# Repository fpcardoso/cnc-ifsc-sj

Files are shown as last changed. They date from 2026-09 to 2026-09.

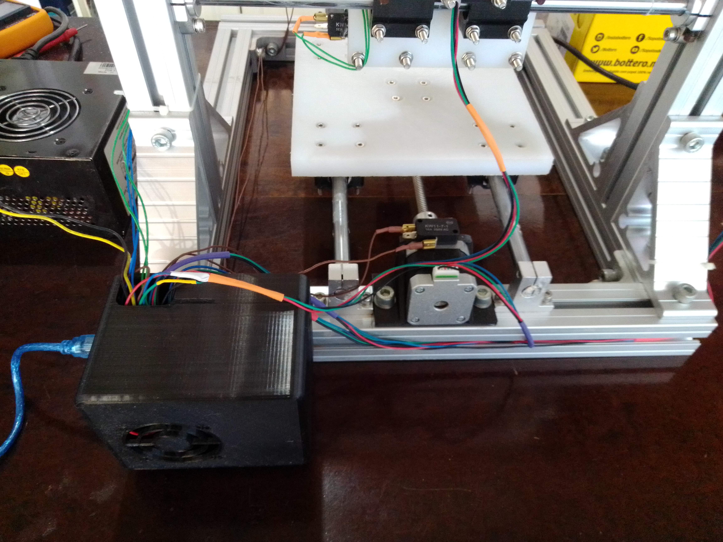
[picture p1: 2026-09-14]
imagens/IMG_20211114_110311.jpg

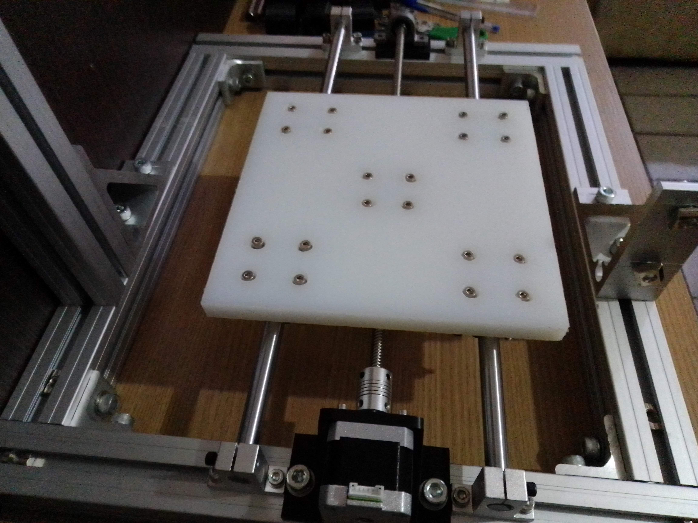
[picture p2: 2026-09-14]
imagens/IMG_20210815_180117.jpg

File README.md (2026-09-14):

# Desenvolvimento de uma fresadora CNC para confecção de antenas planares e PCIs

Este repositório contém os arquivos de modelagem, código-fonte e artefatos utilizados no desenvolvimento de uma **fresadora CNC de pequeno porte**, criada para a fabricação de **antenas planares** e **circuitos impressos (PCIs)** em ambiente acadêmico. O projeto foi desenvolvido como Trabalho de Conclusão de Curso no **Instituto Federal de Santa Catarina (IFSC) -- Câmpus São José**.

## Objetivo do Projeto

Construir uma fresadora CNC acessível, utilizando componentes de **baixo
custo**, **fácil aquisição** e **plataformas abertas**, permitindo:

-   Produção de antenas impressas;
-   Fabricação de PCIs simples por fresamento;

## Características Principais

-   Arquitetura: **CNC vertical de pórtico fixo**.
-   Eixos X, Y e Z controlados por motores **NEMA 17**.
-   Estrutura construída com **perfis de alumínio estrutural**.
-   Guias lineares com **eixos retificados de 12 mm e rolamentos
    LM12UU**.
-   Movimento por **fusos trapezoidais TR8** com castanhas
    **antifolga**.
-   Spindle baseado no motor **775** com suporte **ER11**.
-   Eletrônica simples:
    -   **Arduino Uno**
    -   **CNC Shield V3**
    -   **Drivers A4988**
    -   **Chaves de fim de curso**
-   Firmware: **Grbl** (open-source).
-   Compatível com softwares de envio de G-code, como **Universal Gcode Sender**.

## Documentação Completa

O documento completo do projeto, incluindo modelagem, lista
de materiais, testes, cálculos e guia de operação, está disponível em [TCC_DESENVOLVIMENTO_FRESADORA_CNC](https://repositorio.ifsc.edu.br/items/885bb8a0-5da8-42db-98ac-e9bbe950c8d6).

## Imagens e vídeos

Imagens e vídeos extras do processo de construção estão diponível em [Imagens](./imagens/)

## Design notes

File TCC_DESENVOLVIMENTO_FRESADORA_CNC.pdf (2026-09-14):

### INSTITUTO FEDERAL DE EDUCAÇÃO, CIÊNCIA E TECNOLOGIA

### DE SANTA CATARINA

### CAMPUS SÃO JOSÉ

### FELIPE DOS PASSOS CARDOSO

DESENVOLVIMENTO DE UMA FRESADORA CNC PARA CONFECÇÃO DE ANTENAS PLANARES

### SÃO JOSÉ

2025

### Felipe dos Passos Cardoso

### Desenvolvimento de uma fresadora CNC para confecção de antenas

### planares

Monografia apresentada ao Curso de Engenharia de Telecomunicações do Instituto Federal de Santa Catarina, para a obtenção do título de bacharel em Engenharia de Telecomunicações.

Área de concentração: Telecomunicações

Orientadora: Profa. Evanaska Maria Barbosa Nogueira, Dra.

### São José

### Felipe dos Passos Cardoso

### Desenvolvimento de uma fresadora CNC para confecção de antenas planares

Monografia apresentada ao Curso de Engenharia de Telecomunicações do Instituto Federal de Santa Catarina, para a obtenção do título de bacharel em Engenharia de Telecomunicações.

São José, 19 de dezembro de 2025.

Profa. Evanaska Maria Barbosa Nogueira, Dra.

Instituto Federal de Santa Catarina

Prof. Diego da Silva Medeiros, Dr.

Instituto Federal de Santa Catarina

Prof. Ramon Mayor Martins, Dr.

Instituto Federal de Santa Catarina

# RESUMO

Os dispositivos de comunicação sem fio exercem um papel fundamental na troca de informações e utilizam antenas como elementos essenciais para a transmissão e recepção de ondas eletromagnéticas. Com a crescente demanda por equipamentos mais compactos e eficientes, intensificam-se as pesquisas envolvendo antenas planares, que se destacam pela facilidade de integração e baixo perfil. Entretanto, o desenvolvimento desse tipo de antena apresenta desafios na etapa de fabricação, especialmente no que se refere à precisão e ao custo dos equipamentos necessários, o que pode limitar sua aplicação em ambientes acadêmicos. Uma alternativa para essa problemática é a utilização de máquinas de Comando Numérico Computadorizado (CNC) para a confecção das antenas por meio do processo de fresamento. Nesse contexto, este trabalho teve como objetivo o desenvolvimento de uma fresadora CNC de pequeno porte, utilizando componentes acessíveis, visando sua aplicação no ensino e na pesquisa. O projeto contemplou as etapas de concepção mecânica, integração eletrônica e implementação do sistema de controle. Os testes realizados permitiram validar o funcionamento do sistema de movimentação e do controle da máquina, bem como a execução de simulações completas de usinagem. Embora não tenha sido possível a fabricação física de uma antena planar devido a limitações no sistema de usinagem, os resultados obtidos demonstram a viabilidade da fresadora desenvolvida como uma plataforma funcional e passível de aprimoramentos futuros para aplicações acadêmicas.

Palavras-chave: Fresadora CNC. Antenas impressas. PCI. Prototipagem.

# ABSTRACT

Wireless communication devices play a fundamental role in information exchange and rely on antennas as essential components for the transmission and reception of electromagnetic waves. With the increasing demand for more compact and efficient equipment, research on planar antennas has intensified due to their low profile and ease of integration. However, the development of this type of antenna presents challenges in the manufacturing stage, particularly regarding precision and the high cost of machining equipment, which may limit its use in academic environments. An alternative to this issue is the use of Computer Numerical Control (CNC) machines to manufacture antennas through the milling process. In this context, this work aimed to develop a small-scale CNC milling machine using readily available components, with a focus on applications in teaching and research. The project included the mechanical design, electronic integration, and implementation of the control system. The performed tests validated the operation of the motion system and machine control, as well as complete machining simulations. Although the physical fabrication of a planar antenna was not achieved due to limitations in the machining system, the obtained results demonstrate the feasibility of the developed CNC machine as a functional platform with potential for future improvements in academic applications.

Keywords: CNC milling machine. Printed antennas. PCB. Prototyping.

# LISTA DE ILUSTRAÇÕES

Figura 17 – Imagens ilustrativas do fuso trapezoidal e da castanha antifolga . . . . 31

Figura 21 – Imagens ilustrativas dos suportes KP08 e SHF12 e do acoplador . . . . 33

Figura 28 – Imagem ilustrativa da fonte de alimentação utilizada na fresadora . . . 37

Figura 32 – Conjunto pillow blocks SC12UU customizados para mesa do eixo X . . 43

Figura 34 – Imagens ilustrativas da fresadora com sistemas de deslocamento . . . . 44

Figura 40 – Esquemático do circuito para conexão dos motores à CNC Shield . . . 49 Figura 41 – Esquemático do circuito para conexão das chaves de fim de curso . . . 50

Figura 43 – Esquemático do circuito do spindle com módulo relé e CNC Shield . . 51

Figura 49 – Dimensões do fuso trapezoidal e castanha antifolga em milímetros (mm) 66 Figura 50 – Imagens ilustrativas dos pillow blocks para rolamento e castanha antifolga 66

Figura 60 – Importação do código-fonte do firmware Grbl no software Arduino IDE 76 Figura 61 – Configuração para desabilitar o controle de velocidade do motor 775 . . 76 Figura 62 – Configuração para inverter lógico do pino de acionamento do motor 775 76

Figura 64 – Configurando Arduino Uno no software Universal Gcode Sender (UGS) 77 Figura 65 – Informação de conexão com o firmware no console do software UGS . . 77 Figura 66 – Valores padrões de parâmetros do firmware apresentados no UGS . . . 78

# LISTA DE QUADROS

Quadro 1 – Configurações de resolução de micropassos disponíveis para driver A4988 45

# LISTA DE TABELAS

Tabela 3 – Medidas e quantidades dos elementos mecânicos dimensionados . . . . 39 Tabela 4 – Descrição e valores das variáveis utilizadas no cálculo de steps/mm . . 53 Tabela 5 – Parâmetros ajustados no firmware Grbl para fresadora desenvolvida . . 54

# LISTA DE ABREVIATURAS E SIGLAS

CAD Computer-Aided Design.

CAM Computer-Aided Manufacturing.

CNC Comando Numérico Computadorizado.

IDE Integrated Development Environment.

IFSC Instituto Federal de Santa Catarina.

MDF Medium Density Fiberboard.

PCI Placa de Circuito Impresso.

UGS Universal Gcode Sender.

USB Universal Serial Bus.

# SUMÁRIO

APÊNDICES | 63

APÊNDICE A – LISTA DE COMPONENTES UTILIZADOS . . . . 64

APÊNDICE B – VISTAS DO MODELO 3D DA FRESADORA . . 71

APÊNDICE C – INSTALAÇÃO E PARAMETRIZAÇÃO DO FIRMWARE

APÊNDICE D – GUIA DE OPERAÇÃO DA FRESADORA CNC . . 79

# 1 INTRODUÇÃO

Dispositivos de comunicação sem fio são utilizados em diversos cenários, incluindo residências e setores industriais, desempenhando um papel essencial na troca de informações e conexões globais. Nesses equipamentos, as informações são transmitidas e recebidas por meio de ondas eletromagnéticas, o que torna as antenas um componente crucial na comunicação sem fio. Com os avanços tecnológicos contínuos, esses dispositivos estão se tornando mais complexos em termos de processamento e mais eficientes no consumo de energia, além dos tamanhos se tornarem cada vez mais compactos (PIRES; SILVA, 2017). Como resultado, a indústria está em busca de antenas menores e mais eficientes.

As antenas de microfita, incluindo patch, monopolo impresso e PIFA (Planar Inverted-F Antenna), são amplamente utilizadas em dispositivos de comunicações sem fio. As antenas do tipo patch possuem um elemento irradiante impresso sobre um substrato dielétrico, com um plano de terra oposto e se destacam pelo baixo custo, adaptabilidade a diferentes superfícies, capacidade de assumir vários formatos e tamanho compacto (OLIVEIRA, 2008). Isso possibilita sua integração em dispositivos móveis que compõem os sistemas de telecomunicações.

O desenvolvimento de antenas para dispositivos sem fio é resultado do aprofundamento em pesquisas e experimentações, especialmente aquelas envolvendo antenas impressas para as frequências de micro-ondas. Segundo Pires e Silva (2017), a diversidade de aplicações das antenas impressas, juntamente com questões como o acoplamento da linha de transmissão, diagrama de irradiação desejado, ganho necessário e polarização requerida, justifica amplamente a pesquisa e desenvolvimento contínuo dessas antenas. Isso tem como objetivo aprimorar as características e explorar novos cenários de utilização dessas antenas.

Projetar e fabricar antenas em substratos são atividades complexas que desafiam engenheiros e pesquisadores. A etapa de fabricação desempenha um papel crucial na produção de antenas impressas em substratos, mas a busca pela robustez e precisão resulta na utilização de equipamentos de alto custo. Esse custo elevado pode tornar inviável a utilização desses equipamentos em ambientes educacionais dentro de uma instituição. Uma solução promissora para essa etapa é a adoção de uma fresadora CNC de pequeno porte, uma máquina de usinagem que utiliza a tecnologia de Comando Numérico Computadorizado (CNC) para automatizar o processo de produção de peças, exigindo pouca intervenção do operador (POLASTRINI, 2016).

A usinagem abrange diversos processos de fabricação nos quais ocorre a remoção de material de forma controlada de um objeto original. Esses processos incluem o fresamento, a furação e o torneamento, resultando na criação de peças com a forma desejada (CAVENAGHI; CAVENAGHI; GONZALEZ, 2022). Uma fresadora CNC fabrica a peça por meio do fresamento, processo no qual a ferramenta gira enquanto a mesa movimenta a peça nos eixos longitudinal e transversal. Essa característica única diferencia o fresamento de outros processos de usinagem, proporcionando à fresadora a capacidade de executar uma ampla variedade de trabalhos com precisão (COSTA, 2003).

No câmpus São José do Instituto Federal de Santa Catarina (IFSC), o projeto de pesquisa e extensão intitulado Estudo e desenvolvimento de antenas planares de baixo custo¹ visou o aprofundamento dos estudos sobre antenas impressas e sua implementação em substratos de baixo custo. Buscando preencher, dessa forma, uma lacuna significativa no ensino e pesquisa na área de circuitos de radiofrequência na banda de micro-ondas. O projeto foi dividido em 2 eixos principais de atividades a serem executadas: 1) atividades para concepção e implementação das antenas e; 2) construção de uma máquina CNC para fabricação da antenas planejadas durante a execução do eixo 1.

Este trabalho tem como objetivo principal o desenvolvimento de uma fresadora CNC de pequeno porte e com baixo custo, integrando componentes de hardware e software abertos amplamente aceitos. A fresadora será voltada para a fabricação de antenas impressas, visando atender as necessidades do eixo 1 do projeto mencionando anteriormente. Além disso, a fresadora poderá ser utilizada na produção de outros circuitos impressos, auxiliando na modernização dos projetos integradores e enriquecendo o processo de aprendizagem nas disciplinas que envolvem eletrônica no câmpus São José do Instituto Federal de Santa Catarina (IFSC).

## 1.1 OBJETIVO GERAL

Desenvolver e fabricar uma fresadora CNC de pequeno porte, possibilitando a confecção de antenas planares e outros circuitos impressos.

## 1.2 OBJETIVOS ESPECÍFICOS

1. Pesquisar soluções já implementadas de fresadoras CNC de pequeno porte;
2. Definir os elementos de hardware e software da fresadora proposta;
3. Modelar a estrutura e a disposição dos componentes da fresadora CNC;
4. Montar e configurar a fresadora;
5. Escrever guia de operação da fresadora CNC.

1 Chamada interna No. 51/2019/PROPPI do câmpus São José - IFSC

6. Testar a fresadora com a confecção de um protótipo de antena impressa;

## 1.3 ORGANIZAÇÃO DO TEXTO

O restante do documento está organizado da seguinte forma:

- Capítulo 2 — Revisão bibliográfica: apresenta os conceitos, tecnologias e

fundamentos necessários para o desenvolvimento do projeto.

- Capítulo 3 — Desenvolvimento: descreve o processo completo de construção da

fresadora, incluindo:

– Requisitos do projeto;

– Definição do tipo de fresadora e seus principais elementos;

– Modelagem, dimensionamento e disposição dos componentes;

– Etapas de montagem e configuração;

– Elaboração do guia de operação.

- Capítulo 4 — Resultados: apresenta os resultados obtidos durante as etapas de

desenvolvimento da fresadora CNC, bem como as limitações observadas nos testes.

- Capítulo 5 — Conclusões: discute as contribuições alcançadas pelo projeto,

as lições aprendidas no processo de desenvolvimento e as possíveis melhorias e continuação do trabalho.

# 2 REVISÃO BIBLIOGRÁFICA

Esta seção apresenta uma breve revisão bibliográfica destacando os conceitos e tecnologias utilizados durante o desenvolvimento das atividades. Além disso, apresenta trabalhos relacionados que serviram como base para a construção da fresadora CNC.

## 2.1 MÁQUINAS CNC

Uma máquina CNC pode ser entendida como sendo um equipamento que utiliza a tecnologia de Comando Numérico Computadorizado (CNC) para produção de peças em um processo automatizado com pouca interação de um operador (POLASTRINI, 2016). As características de uma máquina CNC são geralmente identificadas por sua estrutura física, apesar das semelhanças entre diferentes tipos. Cada máquina tem sua própria forma de funcionamento e aplicação, embora possam produzir o mesmo resultado final. Alguns tipos de máquinas CNCs são: impressoras 3D, tornos ou fresadoras CNC (AMORIM; FILHO; ROSA, 2019).

2.1.1 Fresadora CNC

Uma fresadora CNC possui em sua estrutura dois elementos principais: o eixo-árvore e a mesa de trabalho, conforme ilustrado na Figura 1. O eixo-árvore é o elemento principal da máquina, responsável por sustentar e acionar a ferramenta de corte (fresa). Essa ferramenta executa o processo de remoção do material de forma controlada da peça original (material bruto a ser usinado) até chegar ao objeto com a forma desejada (POLASTRINI, 2016).

Figura 1 – Representação de um fresadora CNC vertical

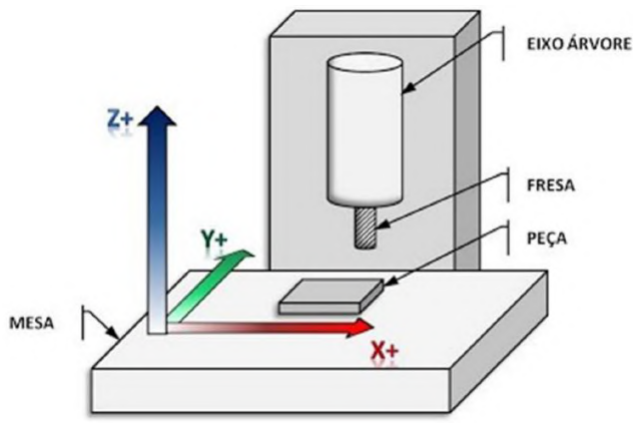
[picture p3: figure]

Fonte: (AZEVEDO, 2013)

A peça original é fixada sobre a mesa de trabalho, que pode movimentar-se nos eixos longitudinal (X) e transversal (Y). Em alguns modelos de fresadora CNC, a mesa pode permanecer estática, cabendo ao eixo-árvore (eixo Z) executar todos os deslocamentos necessários. Essa característica define o tipo de arquitetura da fresadora e está diretamente relacionada à sua capacidade de usinar diferentes materiais e geometrias com alta precisão (COSTA, 2003).

2.1.2 Tipos de Fresadoras CNC

Fresadoras CNC podem ser classificadas de acordo com o tipo de orientação do eixo-árvore em relação à mesa de trabalho. Uma fresadora vertical é aquela que tem o eixo-árvore perpendicular à mesa de trabalho, enquanto que na fresadora horizontal, o eixo principal e a mesa de trabalho estão alinhados paralelamente (SANCHES, 2009). De acordo com Sanches (2009), as fresadoras mais comuns são do tipo vertical e com sua estrutura composta por três eixos denominados X, Y e Z, que são interpretados semelhante ao espaço cartesiano (veja Figura 1). Esse tipo de fresadora CNC é formado por uma estrutura chamada de pórtico, representando o eixo X e o eixo Z (eixo-árvore), além da mesa de trabalho, onde fica o eixo Y. A fresadora vertical pode ser divida em dois subtipos com relação à fixação do seu pórtico: móvel e fixo.

Pórtico móvel

Na fresadora CNC com pórtico móvel, a estrutura do pórtico desloca-se sobre as guias ou trilhos fixados na mesa de trabalho (veja Figura 2). Apesar de fornecer um projeto mais compacto, exige um maior nível de complexidade na construção e a precisão depende muito da sincronia e alinhamento entre os componentes (LEAL; RIBAS, 2015).

Figura 2 – Representação de um fresadora vertical de pórtico móvel

Fonte: Adaptado de (LEAL; RIBAS, 2015)

Pórtico fixo

A fresadora com pórtico fixo é construída com a mesa de trabalho móvel deslocandose sobre guias ou trilhos e a estrutura do pórtico fixada sobre uma base (veja Figura 3). Uma vez que o pórtico é composto pela maior parte dos componentes de uma fresadora vertical, esse tipo de máquina possui um menor deslocamento de massa e uma maior facilidade na montagem (LEAL; RIBAS, 2015).

Figura 3 – Representação de um fresadora vertical de pórtico fixo

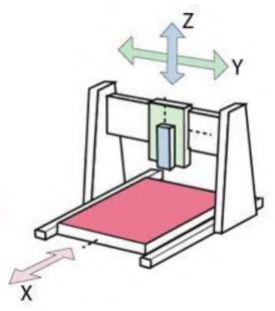
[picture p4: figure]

Fonte: Adaptado de (LEAL; RIBAS, 2015)

## 2.2 ELEMENTOS DE UMA FRESADORA CNC VERTICAL

Segundo Polastrini (2016), a arquitetura de uma fresadora CNC vertical pode ser dividida em:

- Sistemas mecânicos – tipo de material da estrutura principal, das mesas de

trabalho e dos eixos, componentes de fixação e também os mecanismos utilizados para os sistemas de deslocamento e tração;

- Componentes eletrônicos – motores para sistema de tração, sensores de fim de

curso, atuadores, placa controladora, driver de acionamento e fonte de alimentação;

- Ferramenta de corte – motor de usinagem (spindle), pinça de fixação e fresas

(peças para remoção do material);

- Sistema embarcado – firmware da placa controladora.

2.2.1 Estrutura principal, mesas e componentes de fixação

A estrutura principal de uma fresadora CNC corresponde à base onde são fixadas as mesas dos eixos, a mesa de trabalho e os demais elementos. Essa estrutura deve apresentar rigidez estática e dinâmica adequadas, estabilidade dimensional e térmica, além de facilidade de montagem. A escolha do tipo, formato e material da estrutura principal bem como das mesas e dos componentes de fixação influencia diretamente na precisão e qualidade final das peças usinadas (SANCHES, 2009).

Materiais para estrutura principal

Em projetos de baixo custo, a escolha do material para estrutura principal visa alcançar o equilíbrio entre resistência mecânica, peso e viabilidade econômica. Dentre as opções mais comuns, destacam-se os tubos de aço retangulares (CAVENAGHI; CAVE-NAGHI; GONZALEZ, 2022), os perfis de alumínio estruturais (POLASTRINI, 2016) e as chapas de madeira MDF (NARDI, 2020b).

Os tubos de aço oferecem rigidez alta e boa resistência a vibrações, sendo adequados para estrutura principal e para conexões maiores. Entretanto, a montagem exige uma maior complexidade e custo devido a necessidade de soldagem e usinagem (LEAL; RIBAS, 2015). Já os perfis de alumínio estrutural, conforme ilustrado na Figura 4, representam uma opção de material leve e com formato modular, permitindo montagem por encaixe e fixação com engates rápidos, sem necessidade de solda (POLASTRINI, 2016).

Figura 4 – Exemplo de perfil de alumínio estrutural

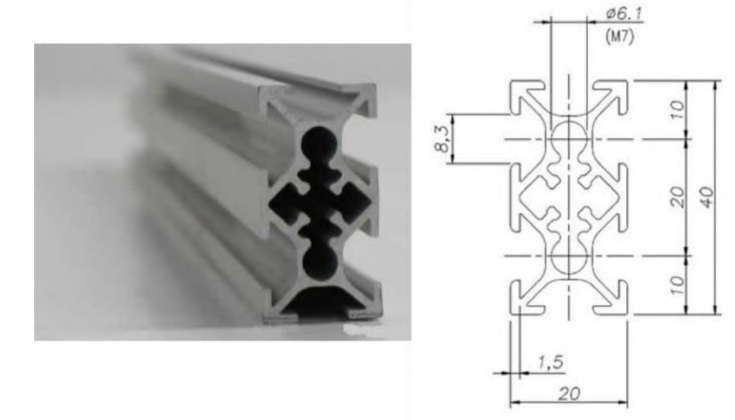
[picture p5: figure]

Fonte: (POLASTRINI, 2016)

As chapas de madeira MDF (veja Figura 5), por sua vez, são frequentemente utilizadas em versões experimentais e protótipos de baixo custo, devido ao fácil manuseio e baixo preço. Apesar disso, sua menor rigidez e facilidade de absorção de umidade limitam seu uso, como estrutura principal, a soluções temporárias ou em projetos didáticos sem necessidade de precisão maior das peças a serem fabricadas (NARDI, 2018b).

Materiais para mesas

Para as mesas de trabalho e dos eixos, materiais como placas de nylon têm se mostrado adequados, principalmente pela boa resistência ao desgaste e ao atrito, além

Figura 5 – Exemplo de placas de MDF

Fonte: Elaborada pelo autor.

de proporcionarem uma superfície estável para fixação das peças a serem usinadas e dos elementos que compõem os sistemas de tração e deslocamento. Em alguns projetos, o uso de chapas de MDF ou de Aluminium Composite Material (ACM)(Figura 6) também é adotado como alternativa de baixo custo e fácil substituição em casos de desgaste (POLASTRINI, 2016).

Figura 6 – Exemplo de placas ACM

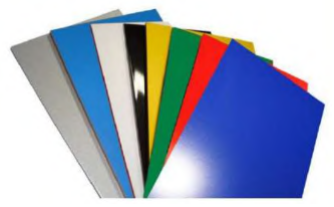
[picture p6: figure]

Fonte: (POLASTRINI, 2016)

Componentes de fixação

Os componentes de fixação desempenham papel essencial na montagem e estabilidade da fresadora CNC, garantindo a união firme entre a estrutura principal, mesas e demais elementos. Em projetos acadêmicos e de baixo custo, é comum a utilização de engates rápidos, parafusos de aço, abraçadeiras e grampos metálicos, por proporcionarem montagem simplificada e facilidade de manutenção (POLASTRINI, 2016; NARDI, 2018b).

Em fresadoras que possuem estrutura principal formada por perfis de alumínio, esses componentes permitem ajustes modulares e reposicionamento sem a necessidade de soldagem. Já nos modelos que utilizam tubos de aço, a fixação geralmente envolve uniões rosqueadas ou soldadas, o que aumenta a rigidez estrutural, mas reduz a flexibilidade para modificações (LEAL; RIBAS, 2015).

2.2.2 Mecanismos de deslocamento e tração

Em fresadoras CNC, a movimentação linear das mesas sobre os eixos é obtida por sistemas de deslocamento e de tração, que podem incluir parafusos de potência, correias dentadas e rolamentos lineares (LEAL; RIBAS, 2015; SANCHES, 2009).

Mecanismos de tração

Os parafusos de potência são elementos mecânicos responsáveis por converter o movimento rotacional do motor em deslocamento linear, sendo essenciais para o posicionamento preciso dos eixos de uma máquina CNC. Entre os modelos existentes, o fuso de rosca trapezoidal (veja exemplo na Figura 7) destaca-se pelo baixo custo e facilidade de fabricação, além de oferecer boa capacidade de carga e operação bidirecional (LEAL; RIBAS, 2015).

Figura 7 – Exemplo de fuso trapezoidal

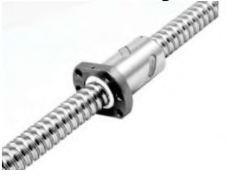
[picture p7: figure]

Fonte: (POLASTRINI, 2016)

Em fresadoras CNC de pequeno porte, fusos trapezoidais são amplamente utilizados por sua resistência, simplicidade construtiva e boa capacidade de carga. Modelos com passo de 8 mm suportam aproximadamente 5 kg no eixo Z, enquanto versões de maior diâmetro, como o TR45, podem sustentar até 26 kg, valores que atendem plenamente às exigências dessas máquinas. Para aprimorar a precisão do sistema, é comum o uso de castanhas ou porcas anti-folga, que mantêm contato constante com o filete do fuso e reduzem o jogo axial, garantindo maior estabilidade e precisão na reversão dos movimentos (CAVENAGHI; CAVENAGHI; GONZALEZ, 2022).

A aplicação dos fusos está diretamente relacionada ao sistema de tração adotado em cada eixo da máquina. Nos eixos X e Y, caracterizados por maiores deslocamentos, é comum a utilização de correias dentadas com polias (veja Figura 8), pois permitem velocidades mais elevadas e baixo custo de implementação. Já no eixo Z, sujeito à força da gravidade, os fusos são preferidos por garantirem melhor sustentação de carga e maior precisão de posicionamento (POLASTRINI, 2016).

Figura 8 – Exemplo de correia dentada e polias

Fonte: Elaborada pelo autor.

Mecanismos de deslocamento

O sistema de deslocamento é responsável por assegurar a precisão dos movimentos e a estabilidade das mesas (POLASTRINI, 2016). Em máquinas CNC de pequeno porte, o conjunto formado por trilhos (guias) e rolamentos lineares mostra-se adequado por combinar baixo custo, fácil montagem e boa precisão. Nesse tipo de sistema, utilizamse eixos de aço retificados e rolamentos lineares de esferas (veja Figura 9), garantindo movimento suave e com baixo atrito (SANCHES, 2009).

Figura 9 – Exemplo de eixos retificado e rolamentos lineares

Fonte: Elaborada pelo autor.

2.2.3 Componentes eletrônicos e firmware

Os componentes eletrônicos, juntamente com o firmware, constituem o núcleo de controle e acionamento da fresadora CNC, convertendo comandos em movimentos precisos dos eixos e da ferramenta de usinagem (POLASTRINI, 2016). Entre os principais elementos destacam-se os motores de passo, os sensores de fim de curso, a placa controladora, os drivers de acionamento, a fonte de alimentação e o firmware.

A fonte de alimentação fornece energia aos componentes e deve ser dimensionada conforme o consumo dos motores. Fontes ATX de 12 V são comuns em versões simples, enquanto modelos de 24 V e 20 A oferecem maior estabilidade e desempenho (LEAL; RIBAS, 2015).

Figura 10 – Placa controladora Arduino UNO

Fonte: (POLASTRINI, 2016)

A placa controladora interpreta comandos G-code e coordena os motores. O Arduino UNO (veja exemplo na Figura 10), baseado no microcontrolador ATmega328p, é amplamente adotado por sua simplicidade e suporte comunitário. Em projetos mais complexos, o Arduino Mega 2560 é utilizado por disponibilizar mais portas de entrada e saída (POLASTRINI, 2016).

Os drivers de acionamento amplificam os pulsos de controle da placa controladora, fornecendo corrente e tensão adequadas aos motores. O A4988 (veja Figura 11) é o modelo mais popular, permitindo controle por micropassos e suporte a correntes de até 2 A. Alternativamente, módulos com L297 e L298 podem ser empregados, associando controle lógico e potência (CAVENAGHI; CAVENAGHI; GONZALEZ, 2022).

Figura 11 – Driver de acionamento A4988

Fonte: (POLASTRINI, 2016)

Os motores de passo (veja exemplo na Figura 12), como os modelos Nema 17 e Nema 23, são amplamente utilizados em projetos de CNC por aliarem precisão, baixo custo e fácil controle. Operam em malha aberta e transformam pulsos elétricos em incrementos de rotação, dispensando sistemas de realimentação. O uso de micropassos aumenta a resolução de movimento, embora reduza o torque disponível (LEAL; RIBAS, 2015).

Os sensores de fim de curso delimitam o deslocamento dos eixos e auxiliam na referência de posição. Em projetos acadêmicos, são comuns sensores mecânicos simples, que oferecem boa durabilidade e integração direta com o firmware (LEAL; RIBAS, 2015).

Por fim, o firmware embarcado na placa controladora integra todos os com-

Figura 12 – Exemplo de motor de passo

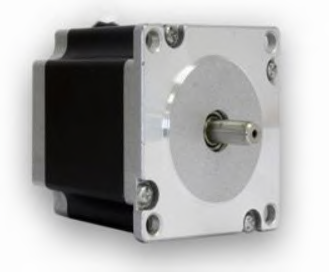
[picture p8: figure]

Fonte: (LEAL; RIBAS, 2015)

ponentes e executa o controle de baixo nível da máquina. Implementações como Grbl e Marlin são amplamente utilizadas, permitindo ajustar parâmetros de movimentação, aceleração e limites de curso. A comunicação é realizada via serial com a linguagem G-code (RS-274D), que define a trajetória, velocidade e rotação do eixo-árvore (POLASTRINI, 2016).

2.2.4 Ferramenta de corte

Em uma fresadora CNC, a ferramenta de corte é responsável pela remoção controlada de material, processo conhecido como usinagem. A ferramenta é sustentada e acionada pelo eixo-árvore (spindle), composto por um motor de alta rotação contínua. Em projetos de baixo custo, podem ser utilizadas micro retíficas comerciais, como a Western, acopladas ao eixo Z da máquina (POLASTRINI, 2016).

Figura 13 – Micro retífica Western

Fonte: (POLASTRINI, 2016)

A fresa é a peça rotativa com arestas cortantes, fixada ao eixo-árvore por pinça ou, de forma mais versátil, mandril, permitindo o uso de ferramentas de diferentes diâmetros. O mandril é a solução mais recomendada por sua facilidade de aquisição e versatilidade (LEAL; RIBAS, 2015).

A grande versatilidade do fresamento decorre das diversas geometrias de fresas, projetadas para operações de desbaste, furação, acabamento ou gravação (veja exemplos na Figura 12). Em usinagem de placas de circuito impresso (PCI), são comuns fresas com ângulo agudo (10° a 20°), que proporcionam maior resolução (POLASTRINI, 2016).

Figura 14 – Exemplos de fresas

Fonte: (POLASTRINI, 2016)

## 2.3 PLACA DE CIRCUITO IMPRESSO

As Placa de Circuito Impressos (PCIs) são componentes essenciais em toda a indústria eletrônica. Elas consistem em placas onde com trilhas condutoras de cobre que podem ser impressas ou depositadas. Enquanto a placa atua como um isolante dielétrico, as trilhas têm a importante função de estabelecer conexões elétricas entre os diversos componentes e as suas respectivas funções dentro do circuito (SOUSA et al., 2001).

Segundo Rodrigues et al. (2019), o processo de confecção de Placa de Circuito Impresso (PCI) envolve várias etapas. Primeiramente, é necessário projetar o layout do circuito usando software de modelagem específico. Em seguida, o layout é transferido para uma placa. Isso é feito por meio de técnicas com processos químicos ou fresagem CNC, para a criação das trilhas condutoras.

No processo com método químico fotográfico, o layout do circuito é transferido para uma placa em branco, geralmente feita de um material isolante, como fibra de vidro ou cerâmica. Em seguida, uma máscara de proteção é aplicada na placa, expondo apenas as áreas onde as trilhas condutoras devem ser formadas. A placa é então imersa em uma solução corrosiva, como ácido férrico ou perclórico, que remove o cobre não protegido, resultando nos circuitos impressos na placa (LIU et al., 2014).

Outro método empregado é o processo que utiliza uma fresadora CNC. Neste método, a CNC é utilizada para eliminar o cobre indesejado de uma placa, deixando somente as trilhas de acordo com o layout do circuito. A fresadora CNC proporciona maior precisão e flexibilidade na criação de PCIs, permitindo a fabricação de circuitos complexos com boa definição das trilhas condutoras (LEAL; RIBAS, 2015).

## 2.4 PROCESSOS DE MODELAGEM E FABRICAÇÃO

O processo de modelagem desempenha um papel essencial no desenvolvimento de produtos, especialmente em projetos que envolvem a fabricação de peças complexas. Esses processos podem ser auxiliados por computadores por meio dos chamados sistemas de processos assistidos por computador, como por exemplo os softwares CAD e CAM (CAVENAGHI; CAVENAGHI; GONZALEZ, 2022). Um dos principais benefícios desses sistemas é possibilitar que a concepção dos projetos aconteça de forma totalmente digital, permitindo depois que sua fabricação ocorra por meio de processos automatizados de usinagem (LEAL; RIBAS, 2015). Essas etapas permitem que os envolvidos no projeto se concentrem mais na parte criativa do desenvolvimento, reduzindo o tempo que levaria na manufatura. Isso contribui diretamente para o aprendizado prático, permitindo que o foco seja direcionado ao desenvolvimento do projeto em si (POLASTRINI, 2016).

2.4.1 Softwares CAD e CAM

O software do tipo Computer-Aided Design (CAD) são utilizados na etapa de concepção da peça, permitindo criar modelos bidimensionais ou tridimensionais que descrevem dimensões como largura, altura, espessura e elementos geométricos como furos ou rebaixos. Além de facilitar a visualização e ajustes do projeto em tempo real, esses sistemas reduzem custos com protótipos físicos e proporcionam maior precisão desde as etapas iniciais (CAVENAGHI; CAVENAGHI; GONZALEZ, 2022).

Após o desenvolvimento do modelo no ambiente CAD, este é exportado para o software do tipo Computer-Aided Manufacturing (CAM), que interpreta as geometrias criadas e gera os percursos que a ferramenta de usinagem deve seguir. Alguns sistemas CAM também oferecem ambientes de simulação, permitindo configurar parâmetros como dimensões da máquina, ferramenta de corte e tipo de fixação, além de prever colisões antes da execução física (POLASTRINI, 2016). Ao final desse processo, o software converte os dados em código de linguagem padrão para comandos de máquinas CNC.

A integração entre esses dois tipos de softwares permite maior agilidade e precisão na fabricação: modificações realizadas no projeto CAD podem ser rapidamente refletidas no CAM, resultando em novos percursos de usinagem sem necessidade de reprogramação manual. Essa sinergia entre os sistemas é um dos fatores que viabilizam a automação acessível na fabricação de peças com boa qualidade e baixo custo (LEAL; RIBAS, 2015).

## 2.5 TRABALHOS RELACIONADOS

Diversos projetos de fresadoras CNC de pequeno porte têm sido desenvolvidos por entusiastas, educadores e pesquisadores, visando disponibilizar alternativas acessíveis para processos de usinagem automatizada. Essas iniciativas exploram componentes de fácil aquisição no mercado e utilizam plataformas abertas de hardware e software, como Arduino e Grbl, favorecendo a adaptação conforme os objetivos de cada aplicação.

Entre as experiências levantadas, destacam-se os tutoriais elaborados por Marlon Nardi, que documentam diferentes versões de fresadoras CNC caseiras. No vídeo referente à versão 2.1 (NARDI, 2018a), são apresentadas instruções completas de montagem de uma máquina baseada em Arduino UNO, drivers A4988 e motores de passo NEMA 17, abrangendo tanto a estrutura mecânica quanto a configuração do firmware. Na versão 3.0 (NARDI, 2018b), o autor propõe avanços na robustez da estrutura e na movimentação dos eixos, resultando em um sistema mais estável e adequado para trabalhos que demandam usinagem de peças maiores.

Na área acadêmica, encontram-se registros de iniciativas com foco educacional. O trabalho de (POLASTRINI, 2016) descreve o desenvolvimento de uma fresadora CNC construída com materiais de baixo custo, direcionada para aplicações em laboratórios de ensino técnico. Complementarmente, (COSTA, 2003) e (CAVENAGHI; CAVENAGHI; GONZALEZ, 2022) oferecem contribuições teóricas relevantes sobre processos de usinagem e operação de fresadoras, fornecendo fundamentos essenciais para o correto dimensionamento e funcionamento dessas máquinas.

Em resumo, os trabalhos analisados evidenciam o potencial educacional das fresadoras CNC de baixo custo, bem como a viabilidade de sua construção a partir de componentes acessíveis e plataformas abertas. Essas iniciativas forneceram a base teórica e prática que orientou o desenvolvimento deste trabalho. O projeto desenvolvido foi inspirado no modelo de baixo custo descrito por (POLASTRINI, 2016) e nas versões incrementais propostas por Marlon Nardi, o qual, além dos vídeos mencionados anteriormente, documentou detalhadamente o processo de desenvolvimento em blogs (NARDI, 2020a; NARDI, 2020b). Esses registros serviram como referência direta para a modelagem e fabricação da fresadora CNC desenvolvida neste trabalho.

# 3 DESENVOLVIMENTO

Este trabalho tem como objetivo principal modelar e construir uma fresadora CNC de pequeno porte, utilizando componentes de hardware e software abertos e que são amplamente aceitos. A fresadora será destinada à fabricação de antenas impressas em substratos de baixo custo, bem como à produção de outros circuitos e protótipos eletrônicos, contribuindo para o aprimoramento do ensino e da pesquisa em dispositivos de telecomunicações em disciplinas da área de eletrônica no câmpus São José do Instituto Federal de Santa Catarina (IFSC).

Este capítulo descreve as atividades executadas, incluindo definição dos requisitos para o projeto, escolha dos componentes da fresadora, modelagem, montagem e configuração da máquina, elaboração do guia de utilização da CNC e, por fim, testes funcionais da fresadora.

## 3.1 REQUISITOS DO PROJETO

Nesta primeira etapa, foram analisados os objetivos do projeto¹ e definidos os
seguintes requisitos esperados para fresadora CNC:

R1: Precisão, estabilidade e robustez para confecção de antenas e circuitos impressos;

R2: Baixo custo para permanecer dentro do orçamento disponibilizado pelo projeto;

R3: Facilidade na montagem, utilização e manutenção;

R4: Utilização de componentes de hardware disponíveis comercialmente;

R5: Utilização de software e firmware de código aberto.

## 3.2 DEFINIÇÃO DO TIPO E DOS ELEMENTOS DA FRESADORA

## PROPOSTA

Considerando os requisitos do projeto (veja seção 3.1), identificou-se que a fresadora do tipo vertical e com pórtico fixo seria a mais adequada, uma vez que as peças a serem usinadas são placas de substrato e não possuem uma massa elevada. De acordo com (LEAL; RIBAS, 2015), esse tipo de fresadora apresenta estrutura mais robusta, construção

1 Estudo e desenvolvimento de antenas planares de baixo custo - chamada interna No. 51/2019/PROPPI do câmpus São José - IFSC simplificada e menor deslocamento de massa durante a operação, pois apenas a mesa de trabalho se move. Essa característica garante maior estabilidade e precisão nos movimentos, o que torna o modelo de fresadora escolhido adequado para fabricação de antenas impressas em substratos.

A revisão bibliográfica e análise das soluções implementadas nos trabalhos relacionados, juntamente com uma pesquisa de mercado realizada para identificar as opções disponíveis, forneceu um panorama dos principais elementos, componentes e tecnologias mais utilizados em fresadoras CNC de pequeno porte e possibilitou a escolha dos elementos e componentes mais adequados às necessidades do projeto. Os principais elementos são detalhados nas subseções a seguir e uma lista completa com a quantidade e custo de todos os componentes utilizados está disponível no Apêndice A.

3.2.1 Sistemas mecânicos

Após a escolha do tipo da fresadora, definiu-se os elementos mecânicos, tais como mecanismos de deslocamento e tração, componentes de fixação e os tipos de materiais para estrutura principal e para as mesas de trabalho e dos eixos. Na Tabela 1 são descritos os elementos, seus tipos e materiais escolhidos e os requisitos que foram atendidos.

Tabela 1 – Elementos mecânicos da fresadora proposta

Elemento | Tipo/Material escolhido | Requisito(s) atendido(s)
Estrutura principal | Perfil de alumínio estrutural | R1, R3 e R4
Mesas de trabalho e dos eixos | Placa de nylon | R1, R3 e R4
Mecanismo de tração | Fusos trapezoidais | R1, R2 e R4
Mecanismo de deslocamento | Eixos retificados com rolamentos lineares | R1, R2 e R4
Elementos de fixação | Parafusos de aço e cantoneiras de alumínio | R1, R2, R3 e R4

Fonte: Elaborada pelo autor.

3.2.1.1 Estrutura principal e Mesas de trabalho e dos eixos

O perfil de alumínio estrutural com formato e dimensões ilustrados na Figura 15 foi escolhido para estrutura principal da fresadora, por se tratar de um material que oferece uma boa resistência mecânica e praticidade na montagem. Além disso, os perfis de alumínio são amplamente comercializados com as medidas de comprimentos desejadas, o que facilita sua aquisição e adaptação ao projeto. A montagem com esse tipo de material é simplificada, dispensando processos complexos como soldagem e eliminando necessidade de ferramentas para corte (POLASTRINI, 2016).

Outros materiais foram considerados para estrutura principal, como placas de Medium Density Fiberboard (MDF) e chapas ou tubos de aço. No entanto, o MDF foi

Figura 15 – Perfil de alumínio definido para estrutura principal

(a) Imagem ilustrativa | (b) Dimensões em milímetros
Fonte: Elaborada pelo autor.

descartado devido à sua baixa resistência à umidade e possibilidade de deformações ao longo do tempo, o que comprometeria a estabilidade da estrutura e não atenderia ao requisito R1 do projeto. Já os tubos ou chapas de aço foram desconsiderados pela maior dificuldade de corte e soldagem, o que impactaria negativamente na viabilidade da construção com os recursos disponíveis e não atenderia ao requisito R3, apesar de terem um custo mais baixo.

Para as mesas de trabalho e dos eixos, foram escolhidas placas de Nylon 6 (poliamida 6 - PA6) com 15 mm de espessura, conforme ilustrado na Figura 16. Esse material apresenta boa rigidez mecânica, facilidade de usinagem (perfuração e corte) e estabilidade para a fixação da peça a ser usinada e dos demais elementos da máquina CNC. Além disso, as placas de Nylon são comercialmente disponíveis em formatos e dimensões customizados, o que facilita sua adaptação a diferentes projetos.

Figura 16 – Exemplos de placas de Nylon com 15 mm de espessura

Fonte: Elaborada pelo autor.

3.2.1.2 Mecanismos de tração e deslocamento

Para o mecanismo de tração, foram adotados fusos trapezoidais de 8 mm de diâmetro (tr8 ) que podem ser acoplados diretamente aos motores de passo. Além disso, o valor da distância percorrida (mm) pelo fuso em cada revolução (360◦
) do fuso (pitch do fuso)
é Dmm/rev = 8. Essas características proporcionam maior precisão e estabilidade nos movimentos, principalmente no eixo Z, onde a sustentação e deslocamento do sistema de usinagem é mais crítica. Para eliminar folgas durante os deslocamentos, utilizou-se castanhas antifolga de cobre, compostas por duas metades ajustáveis com mola, que exercem pressão constante sobre o fuso e compensam automaticamente a folga axial. A Figura 17 ilustra o conjunto de fuso e castanha definido para a fresadora proposta.

Figura 17 – Imagens ilustrativas do fuso trapezoidal e da castanha antifolga

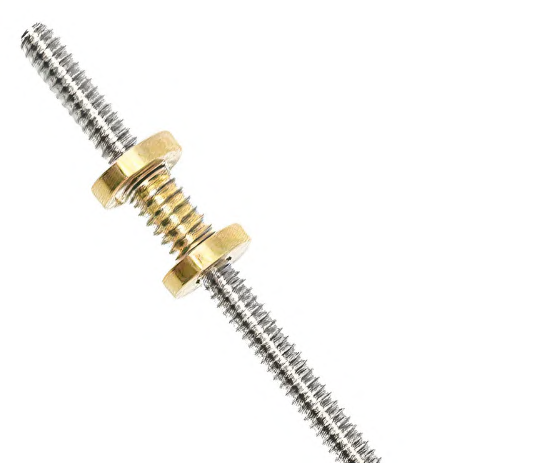
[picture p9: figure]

(a) Fuso trapezoidal tr8 | (b) Castanha antifolga tr8 | (c) Conjunto montado
| Fonte: Próprio autor

O mecanismo de deslocamento, responsável por guiar as mesas nas direções cartesianas, foram definidos com a utilização de eixos retificados de 12 mm de diâmetro com rolamentos lineares modelo LMUU12. A Figura 18 ilustra o conjunto definido para o projeto que, segundo (LEAL; RIBAS, 2015), reduz o atrito durante a operação e assegura ações de repetição no posicionamento da ferramenta. A utilização de rolamentos lineares também minimiza folgas e irregularidades ao longo dos eixos, evitando vibrações e imperfeições na peça usinada.

Figura 18 – Imagens ilustrativas do eixo retificado e rolamento linear

(a) Eixo retificado 12 mm | (b) Rolamento linear LMUU12 | (c) Conjunto montado
| Fonte: Próprio autor

3.2.1.3 Elementos de fixação e suporte

Para a fixação da estrutura principal e dos demais elementos optou-se pela utilização de parafusos de aço, cantoneiras de alumínio e suportes específicos para acoplamento dos componentes mecânicos e dos eixos. A escolha desses elementos teve como objetivo garantir uma montagem modular, permitindo ajustes, desmontagens e manutenções com ferramentas simples. Essa abordagem contribui para a praticidade na construção e para o atendimento do requisito R3, visando uma montagem facilitada e de baixo custo.

Para fixação geral dos elementos da fresadora, tanto na estrutura de perfis de alumínio quanto nos suportes mecânicos, definiu-se a utilização de parafusos do tipo Allen, em conjunto com porcas e arruelas lisas, conforme ilustrado na Figura 19a. No caso específico da fixação dos componentes na estrutura principal, optou-se pelas porcas tipo T, compatíveis com os canais de 8 mm presentes nos perfis de alumínio. Essas porcas, também conhecidas como porcas martelo, encaixam-se nos canais dos perfis e garantem uma fixação firme e ajustável (veja Figura 19b). Essa solução oferece flexibilidade de montagem, possibilitando o reposicionamento e ajustes dos componentes sem a necessidade de furações ou substituição de estrutura.

Figura 19 – Imagens ilustrativas dos parafusos, porcas e arruelas

(a) Parafusos, porcas e arruelas para fixação geral
(b) Porca do tipo T para fixação em perfil de alumínio
Fonte: Elaborada pelo autor.

As cantoneiras de alumínio de 90◦
(ver Figura 20) foram escolhidas para a união dos perfis estruturais, assegurando o alinhamento e a rigidez da estrutura principal da fresadora. Esse tipo de fixação oferece boa resistência mecânica e facilidade de montagem, permitindo que as conexões sejam reforçadas ou ajustadas conforme necessário.

Além desses elementos, foram utilizados suportes específicos para a fixação dos eixos retificados e dos fusos trapezoidais, garantindo o correto posicionamento e o alinhamento dos sistemas de tração e deslocamento. Definiram-se: o mancal KP08 com rolamento, destinado ao apoio dos fusos trapezoidais (Figura 21a); e o suporte SHF para os eixos retificados de 12 mm (Figura 21b). Também foram escolhidos acopladores flexíveis (veja Figura 21c), responsáveis por conectar os fusos trapezoidais aos eixos dos motores de passo,

Figura 20 – Imagens ilustrativas dos tipos de cantoneiras

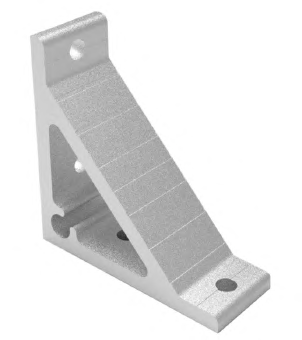
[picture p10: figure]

(a) Cantoneira simples de alumínio | (b) Cantoneira reforçada de alumínio
Fonte: Elaborada pelo autor.

permitindo pequenas compensações de desalinhamento e reduzindo esforços mecânicos indesejados.

Figura 21 – Imagens ilustrativas dos suportes KP08 e SHF12 e do acoplador

(a) Suporte KP08 | (b) Suporte SHF12 | (c) Acoplador (5x8) mm
| Fonte: Próprio autor

Por fim, para o fixação dos rolamentos lineares e da castanha antifolga nas mesas de trabalho e dos eixos, definiu-se os blocos de fixação (também chamados de pillow blocks), conforme modelos ilustrados na Figura 22. Esses suportes oferecem boa estabilidade e facilidade de instalação, além de contribuírem para a redução de vibrações e ruídos durante a operação.

Figura 22 – Imagens ilustrativas dos blocos de fixação (pillow blocks)

(a) Bloco para castanha tr8 | (b) Bloco para rolamento linear
Fonte: Elaborada pelo autor.

3.2.2 Componentes de hardware

Os componentes de hardware podem ser definidos como o conjunto de elementos eletrônicos e eletromecânicos responsáveis pelo comando, controle e operação dos elementos mecânicos da fresadora CNC. Esses elementos realizam funções de interpretação dos comandos de usinagem, acionamento dos motores de passo, controle da ferramenta de corte e gerenciamento da alimentação de todo o sistema.

A escolha desses componentes foi feita com base em critérios como compatibilidade entre os elementos, facilidade de encontrar as peças no mercado, baixo custo e simplicidade na montagem e configuração. A Tabela 2 apresenta a lista dos principais componentes definidos, indicando também quais requisitos do projeto cada um atende e a qual parte do sistema pertence.

Tabela 2 – Componentes de hardware da fresadora proposta

Sistema | Componente(s) escolhido(s) | Requisito(s) atendido(s)
Comando e controle | Arduino Uno + CNC Shield | R2, R4 e R5
| Drivers para motor de passo | R2 e R4
| Módulo relé | R2 e R4
| Chaves de fim de curso | R2 e R4, R3
Tração e deslocamento | Motores de passo para os eixos | R1 e R4
Usinagem | Motor 775 para ferramenta de usinagem | R4
| Eixo suporte ER11 e pinça | R3
| Ferramentas de usinagem (fresas) | R1, R2 e R4
Alimentação | Fonte chaveada para sistema de comando e controle e sistema de tração | R1, R4
| Fonte para motor de usinagem | R1, R4

Fonte: Elaborada pelo autor.

3.2.2.1 Sistema de comando e controle

O sistema de comando e controle é responsável pela interpretação dos comandos de usinagem e pela coordenação dos movimentos dos eixos. Para a fresadora proposta, adotou-se a placa controladora Arduino Uno em conjunto com o módulo CNC Shield v3, conforme ilustrado na Figura 23. Essa combinação foi escolhida por oferecer uma solução acessível, amplamente documentada e compatível com o firmware Grbl, escolhido para realizar o controle preciso dos eixos da máquina CNC por meio de comandos G-code.

A utilização do Arduino Uno também facilita a integração com outros módulos eletrônicos, como sensores e relés, por meio de sua arquitetura aberta e número adequado de pinos digitais e analógicos. A placa CNC Shield v3 atua como uma interface entre o

Figura 23 – Imagens ilustrativas do Arduino Uno e módulo CNC Shield v3

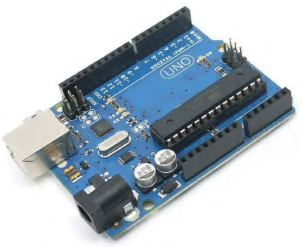
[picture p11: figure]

(a) Placa Arduino Uno | (b) Módulo CNC Shield v3
Fonte: Elaborada pelo autor.

microcontrolador e os drivers dos motores de passo, simplificando as conexões e permitindo ajustes individuais de corrente e micropassos.

Para o acionamento dos motores de passo, foram definidos drivers do modelo A4988, conforme ilustrado na Figura 24a, adequados para motores bipolares de até 2 A por fase, que permitem controle por micropassos e ajuste de corrente. Esses drivers são facilmente acoplados ao CNC Shield v3 (veja Figura 24b), tornando a montagem mais organizada e segura. Além disso, foi adicionado um módulo relé de um canal (veja Figura 24c), utilizado para o controle do motor de usinagem (spindle), possibilitando o acionamento e desligamento automático por comando.

Figura 24 – Imagens ilustrativas do driver A4988 e módulo relé

(a) Driver A4988 | (b) CNC Shield v3 com drivers | (c) Módulo relé
| Fonte: Próprio autor

Por fim, foram definidos para o sistema as chaves de fim de curso (também conhecidas como limit switches) para serem instaladas nas extremidades dos eixos X, Y e Z. Essas chaves têm a função de definir as posições de referência e proteger o sistema contra colisões, interrompendo o movimento caso os limites sejam atingidos.

3.2.2.2 Sistema de tração e deslocamento

Os movimentos dos eixos X, Y e Z são realizados por motores de passo, que transformam os pulsos elétricos enviados pelo controlador em deslocamentos lineares precisos. Foram definidos motores de passo do tipo NEMA 17, amplamente utilizados em aplicações CNC e impressoras 3D, devido ao seu bom equilíbrio entre torque, tamanho e custo. A Figura 25 ilustra o modelo adotado.

Os motores NEMA 17 utilizados possuem torque nominal de aproximadamente 4,2 kgf por cm e quantidade de passos por revolução Nsteps/rev = 200, o que é suficiente para movimentar as mesas de trabalho e dos eixos com estabilidade. Sua escolha também se justificou a escolha dos drivers A4988 e pela facilidade de montagem com acopladores flexíveis, que conectam o eixo do motor aos fusos trapezoidais descritos na seção subseção 3.2.1.3.

Figura 25 – Motor de passo NEMA 17

Fonte: Elaborada pelo autor.

3.2.2.3 Sistema de usinagem

O sistema de usinagem é composto pelo motor responsável pelo giro da ferramenta de corte, eixo de suporte e pelas ferramentas de corte (fresas). Para o motor de usinagem, foi adotado o modelo 775, mostrado na Figura 26a, devido à sua ampla disponibilidade e custo reduzido. Esse motor é de corrente contínua (DC) e apresenta boa rotação (entre 10.000 e 15.000 rpm), adequada para a usinagem de materiais como acrílico, madeira e placas de fenolite, que são compatíveis com o objetivo da fresadora proposta.

Figura 26 – Imagens ilustrativas do motor 775 e eixo de suporte ER11

(a) Motor 775 | (b) Eixo de suporte ER11 | (c) Motor 775 e eixo ER11
| Fonte: Próprio autor

Para o acoplamento da ferramenta de corte ao motor foi definido um eixo de suporte tipo ER11, com diâmetro interno compatível com o eixo de 5 mm do motor 775, conforme ilustrado nas Figuras 26b e 26c. Esse suporte permite o uso de pinças intercambiáveis (veja Figura 27a), garantindo melhor centragem e redução de vibrações durante a usinagem.

As ferramentas de cortes definidas são fresas específicas para usinagem de antenas planares e Placa de Circuito Impressos (PCIs), do tipo V-Carving com eixo de 3,175 mm, fabricadas em metal duro (V-Bit), conforme ilustrado na Figura 27b. Esse tipo de fresa possibilita realizar operações de gravação e desbaste de material superficial com boa precisão e bom acabamento, sendo adequada para o trabalho de isolamento de trilhas e desbates de cobre em placas de fenolite.

Figura 27 – Imagens ilustrativas da pinça e fresas

(a) Pinça para fresa | (b) Fresas tipo V-Carving
Fonte: Elaborada pelo autor.

3.2.2.4 Sistema de alimentação

O sistema de alimentação é responsável por fornecer energia elétrica aos circuitos de comando, motores e demais dispositivos eletrônicos da fresadora. Foram escolhidas duas fontes chaveadas, conforme modelo apresentado na Figura 28: uma com saída de 12 V e 10 A destinada aos motores de passo e ao Arduino; e outra com saída de 12 V e 15 A dedicada ao motor de usinagem (775 DC). As fontes foram escolhidas por sua confiabilidade, disponibilidade comercial e eficiência energética, além de possuírem proteção contra sobrecorrente e sobretensão.

Figura 28 – Imagem ilustrativa da fonte de alimentação utilizada na fresadora

Fonte: Elaborada pelo autor.

## 3.3 MODELAGEM DA FRESADORA

Com o tipo da fresadora e os elementos a serem utilizados definidos, a próxima etapa consistiu na modelagem tridimensional da fresadora utilizando o software CAD SketchUp²
, versão gratuita para estudantes, da empresa Trimble. Esta etapa teve como objetivo planejar o dimensionamento da estrutura e a disposição dos componentes de forma virtual, permitindo realizar ajustes, verificar interferências e validar o projeto antes da montagem física.

3.3.1 Definição da área útil

O ponto de partida para o desenvolvimento da modelagem foi a definição da área útil de usinagem para a fresadora proposta, ou seja, o espaço efetivo da mesa de trabalho disponível para movimentação da ferramenta de corte sobre a peça a ser usinada.

Na definição da área útil, considerou-se inicialmente o tamanho comum das antenas planares impressas para operação em faixas de micro-ondas. Devido a frequência de operação, essas antenas possuem dimensões físicas reduzidas. Também foram analisados os tamanhos padrões das placas de fenolite utilizadas na fabricação de Placa de Circuito Impressos (PCIs), geralmente comercializadas com dimensões de área inferiores a 10x10 cm. Assim, definiu-se uma área útil de 15x15 cm, suficiente para a fabricação de antenas planares e PCI.

3.3.2 Dimensionamento dos elementos mecânicos

O SketchUp, além de ser uma ferramenta Computer-Aided Design (CAD) de fácil utilização, permite a inclusão de modelos tridimensionais fornecidos por fabricantes ou comunidades de usuários, disponíveis em repositórios como o Thingiverse³

e 3D Warehouse⁴
Esses modelos apresentam medidas e geometrias compatíveis com os componentes reais, assegurando maior precisão no dimensionamento e na modelagem da disposição dos elementos da fresadora proposta.

A partir da área útil de usinagem definida (15x15 cm) e do tipo de fresadora adotado (pórtico fixo), foi possível determinar as dimensões dos elementos que compõem o sistema mecânico, cujos materiais e tipos foram previamente definidos na subseção 3.2.1. Nessas condições, a mesa de trabalho foi dimensionada com 20x20 cm, de modo a cobrir integralmente a área útil e permitir a fixação segura das placas de fenolite durante o processo de usinagem.

2 | https://sketchup.trimble.com
3 | https://www.thingiverse.com/
4 | https://3dwarehouse.sketchup.com/

Com base nas dimensões da mesa de trabalho e nos modelos 3D dos componentes importados no SketchUp, foram definidas as medidas dos cursos para os eixos X e Y, garantindo que a máquina consiga deslocar-se por toda a área útil de usinagem. Além disso, foi possível definir também as medidas para o curso do eixo Z para realização do movimento vertical necessário para ajustar a posição da ferramenta de corte.

A partir da definição das medidas desses cursos, foram determinados os comprimentos dos eixos retificados lineares e dos fusos trapezoidais, assegurando o deslocamento total desejado e o alinhamento dos elementos móveis. A partir desses valores, também foram definidos os comprimentos para os perfis de alumínio da estrutura principal, buscando um conjunto rígido e estável, mas sem adicionar peso excessivo.

As medidas das placas de Nylon utilizadas como mesas dos eixos foram definidas conforme a área necessária para fixação dos suportes (pillow blocks) dos rolamentos lineares e das castanhas antifolgas em cada eixo. As medidas e quantidades dos principais elementos do sistema mecânico dimensionados estão apresentadas na Tabela 3. A lista completa de todos os componentes definidos, com suas respectivas dimensões e características, encontra-se detalhada no Apêndice A.

Tabela 3 – Medidas e quantidades dos elementos mecânicos dimensionados

Tipo/Material | Elementos (Medidas) | Qtd
Perfil de alumínio | Base direção eixo Y (comprimento = 395 mm) | 2
| Base direção eixo X (comprimento = 400 mm) | 2
| Pórtico direção eixo Z (comprimento = 300 mm) | 2
| Pórtico direção eixo X (comprimento = 400 mm) | 1
Eixo retificado 12 mm | Eixo Y (comprimento = 450 mm) | 2
| Eixo X (comprimento = 320 mm) | 2
| Eixo Z (comprimento = 170 mm) | 2
Fuso trapezoidal 8 mm | Eixo Y (comprimento = 400 mm) | 1
| Eixo X (comprimento = 360 mm) | 1
| Eixo Z (comprimento = 155 mm) | 1
Placa de Nylon 15 mm | Mesa de trabalho eixo Y (área = 200 mm x 200 mm) | 1
| Mesa eixo X - rolamentos (área = 120 mm x 165 mm) | 1
| Mesa eixo X - castanha (área = 90 mm x 50 mm) | 1
| Mesa eixo Z (área = 120 mm x 55 mm) | 1

Fonte: Elaborada pelo autor.

3.3.3 Disposição dos componentes da Fresadora

Após a definição das dimensões dos elementos mecânicos e considerando que os componentes de dimensões padronizadas, como motores, acoplamentos, mancais e suportes de eixos, foram utilizados de acordo com as medidas fornecidas pelos fabricantes ou obtidas em bibliotecas de modelos 3D, foi possível determinar também a quantidade e as medidas dos elementos de fixação necessários para montagem completa da fresadora.

Além dos componentes padronizados, foram modelados suportes customizados para os motores de passo e para o motor 775 (ferramenta de corte), desenvolvidos especificamente com base na disposição dos elementos implementada no modelo tridimensional do SketchUp. Esses suportes garantem a montagem adequada, contribuindo para a precisão dos movimentos e a estabilidade durante a usinagem.

As Figuras 29 e 30 ilustram as vistas frontal e posterior da fresadora CNC modelada no SketchUp. O Apêndice B reúne outras vistas da modelagem apresentando outros detalhes para construção.

Figura 29 – Vista frontal do modelo 3D da fresadora projetada

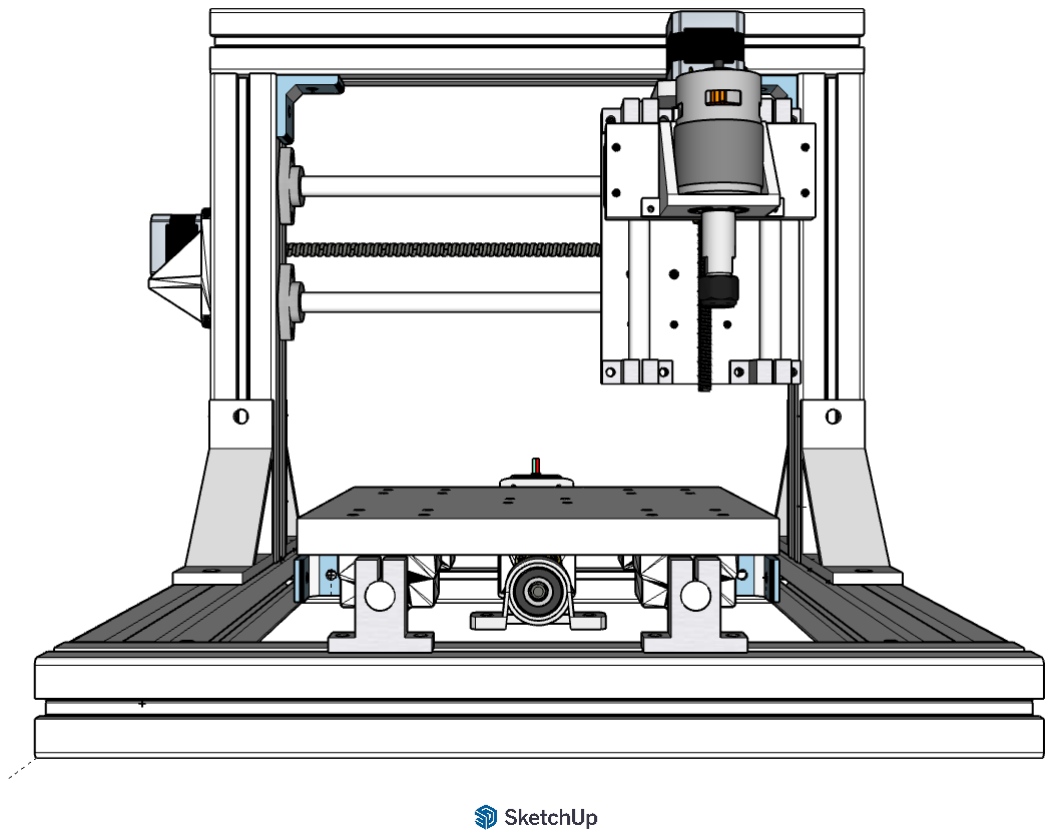
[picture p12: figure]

Fonte: Elaborada pelo autor.

Os arquivos fonte do projeto, incluindo o modelo tridimensional completo da fresadora e os modelos individuais dos componentes customizados e padronizados, estão disponíveis publicamente no repositório cnc-ifsc-sj⁵
, hospedado no GitHub, possibilitando a reprodução ou modificação do projeto por outros pesquisadores e entusiastas.

## 3.4 MONTAGEM E CONFIGURAÇÃO

A construção da fresadora CNC envolveu a integração de elementos mecânicos, eletrônicos e de software. Antes da montagem física, os componentes listados nos quadros do Apêndice A foram adquiridos em lojas especializadas em equipamentos para CNC.

5 https://github.com/fpcardoso/cnc-ifsc-sj

Figura 30 – Vista posterior do modelo 3D da fresadora projetada

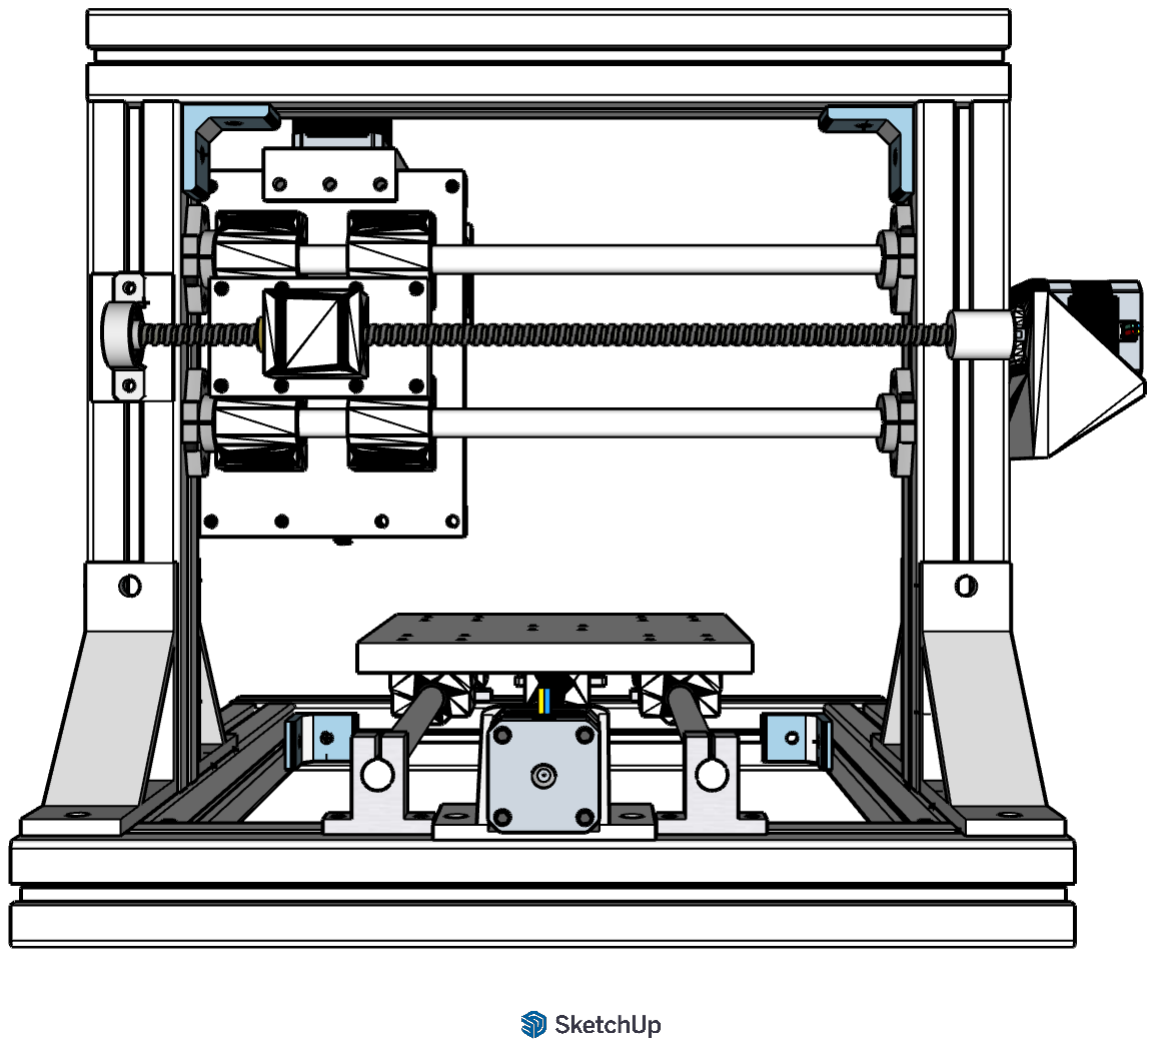
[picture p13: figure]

Fonte: Elaborada pelo autor.

Alguns itens, entretanto, como suportes de motores, pillow blocks e o gabinete eletrônico, foram modelados e fabricados pelo próprio autor utilizando uma impressora 3D.

Não é objetivo deste trabalho detalhar o processo de fabricação com impressora 3D ou fluxo completo de desenvolvimento dos modelos tridimensionais no SketchUp. Dessa forma, nas subseções que houver citação da fabricação de componentes, será informado apenas o nome do arquivo do respectivo modelo 3D utilizado.

A montagem mecânica, a configuração eletrônica e os ajustes do firmware foram realizados de forma sequencial, garantindo precisão geométrica e o funcionamento correto dos elementos. Esta seção apresenta as etapas de montagem e calibração da fresadora desenvolvida. Para fins de organização, os arquivos referenciados correspondem aos modelos do SketchUp e aos códigos do firmware disponíveis no repositório cnc-ifsc-sj⁵

Como ferramentas, utilizaram-se: conjunto de chaves Allen, furadeira de bancada, brocas nos diâmetros dos parafusos especificados, alicate cortador e descascador de fios, fita isolante ou espaguete termoretrátil e conjunto de chaves estrela para as porcas sextavadas.

3.4.1 Montagem da estrutura principal

A estrutura principal foi montada a partir da junção dos perfis de alumínio estrutural utilizando as cantoneiras e demais elementos de fixação apresentados nas seções anteriores e detalhados na subseção A.1.1. Nessa etapa, não foi necessário realizar cortes ou perfurações adicionais. A Figura 31 ilustra o resultado da montagem da estrutura principal.

Figura 31 – Imagens ilustrativas da estrutura principal da fresadora

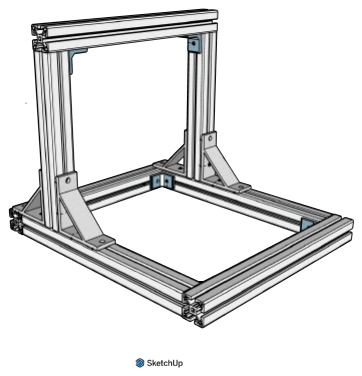
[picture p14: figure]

(a) Vista direita | (b) vista esquerda
| Fonte: Elaborada pelo autor.

3.4.2 Furação das placas de Nylon

Para permitir a fixação dos componentes mecânicos, foram realizados furos nas placas de Nylon que compõem as mesas dos eixos, conforme descrito no Quadro 3 do Apêndice A. Os furos foram executados em uma furadeira de bancada utilizando brocas adequadas para polímeros, seguindo os diâmetros compatíveis com os parafusos especificados nas listas de componentes. As posições dos furos podem ser verificadas no arquivo de modelagem CNC-completa.skp.

3.4.3 Fabricação e instalação dos pillow blocks

Para os mecanismos de deslocamento, foram fabricadas, em impressora 3D, seis unidades de pillow blocks compatíveis com o modelo SC12UU para os eixos Y e Z. Para o eixo X, foram produzidas quatro unidades de pillow blocks SC12UU customizados (arquivo pillow-block_SC12UU_M5-customizado), contendo furos M5 em um dos lados, permitindo a fixação entre duas placas de Nylon conforme a modelagem adotada para esse eixo, ilustrado na Figura 32.

Para os mecanismos de tração, foram fabricadas três unidades de pillow blocks simples destinados às castanhas antifolga, conforme o modelo disponível no arquivo pillow-block_castanha-antifolga.skp.

Após a fabricação, iniciou-se a etapa de instalação dos conjuntos. Cada rolamento linear LM12UU foi encaixado em seu respectivo pillow block (incluindo os customizados), totalizando 12 conjuntos para deslocamento linear. As três castanhas antifolga foram montadas em seus respectivos pillow blocks para tração.

Em seguida, esses conjuntos foram fixados nas mesas dos eixos utilizando os parafusos, porcas e arruelas especificados no Quadro 4 e Quadro 5 do Apêndice A. A Figura 33 apresenta as mesas dos eixos X, Y e Z com os respectivos conjuntos instalados.

Figura 32 – Conjunto pillow blocks SC12UU customizados para mesa do eixo X

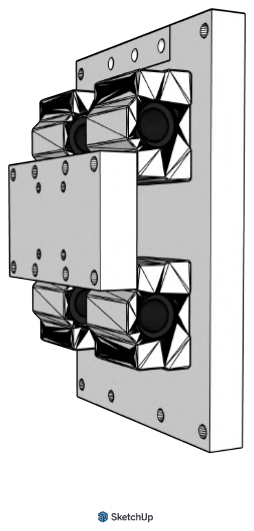
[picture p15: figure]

Fonte: Elaborada pelo autor.

Figura 33 – Imagens das mesas com fixação dos pillow blocks

(a) Mesa eixo Y | (b) Mesa eixo X | (c) Mesa eixo Z
| Fonte: Próprio autor

3.4.4 Instalação dos componentes do sistema de deslocamento

Com os pillow blocks montados nas mesas montadas, iniciou-se a instalação dos sistemas de deslocamento de cada eixo. Cada sistema é composto por um par de eixos retificados, que são encaixados nos pillow blocks de rolamentos fixados nas mesas. Posteriormente, cada ponta dos pares de eixos foi fixado em sua respectiva estrutura utilizando parafusos, arruelas, porcas e suportes conforme detalhado lista do Quadro 4 e descrito a seguir:

- pares do eixo X, fixado com quatro suportes SHF12 nos perfis da base;
- pares do eixo Y, fixado com quatro suportes SK12 nos perfis do pórtico;
- pares do eixo Z, fixado com quatro suportes SK12 na mesa do eixo Y.

A Figura 34 apresenta as vistas do modelo 3D contendo apenas os sistemas de deslocamento montados.

Figura 34 – Imagens ilustrativas da fresadora com sistemas de deslocamento

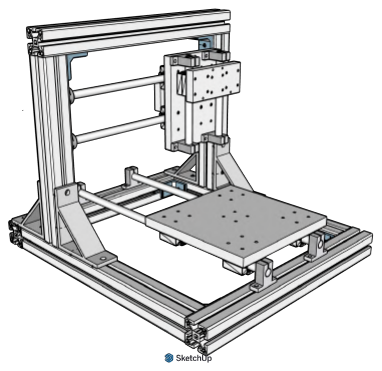
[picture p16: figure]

(a) Vista direita | (b) vista esquerda
| Fonte: Elaborada pelo autor.

3.4.5 Instalação dos componentes do sistema de tração

A etapa de montagem dos sistemas de tração de cada eixo iniciou com o encaixe dos fusos trapezoidais Tr8 nas castanhas antifolga previamente instaladas nos pillow blocks simples de cada mesa. Em seguida, uma das extremidades de cada fuso foi encaixada em um acoplador flexível, que posteriormente foi fixado ao eixo do motor NEMA 17. Nos eixos X e Y, as extremidades opostas dos fusos foram fixadas nas estruturas correspondentes por meio de mancais do tipo KP08, utilizando parafusos, porcas e arruelas conforme especificado no Quadro 5.

A montagem dos motores NEMA 17 foi realizada com a utilização de suportes fabricados em impressora 3D, disponíveis nos arquivos suporte-nema_eixo-X.skp, suporte-nema_eixo-Y.skp e suporte-nema_eixo-Z.skp. A fixação dos motores aos suportes e dos suportes às estruturas (mesas ou perfis de alumínio) foi realizada com parafusos, arruelas e porcas detalhados no Quadro 6. A Figura 35 apresenta as vistas do modelo tridimensional da fresadora com todos os sistemas de tração instalados.

Figura 35 – Imagens ilustrativas da fresadora com sistemas de tração

(a) Vista direita | (b) vista esquerda
| Fonte: Elaborada pelo autor.

3.4.6 Sistema de comando e controle

Para a montagem do sistema de comando e controle da fresadora, foi fabricado um gabinete impresso em 3D, com tampa de proteção, para fixação do conjunto principal composto pelo Arduino Uno, pela placa CNC Shield v3 e pelos drivers A4988. Além disso, foi instalado o módulo relé e organizado todos os componentes eletrônicos e fiação dos circuitos necessários para o sistema.

O processo de montagem dos componentes que compõem o sistema de comando e controle utilizou a lista apresentada no Quadro 7 e envolveu etapas como instalação, conexão elétrica e cálculos necessários para a definição das configurações dos componentes, as quais são detalhadas nas subseções a seguir.

3.4.6.1 Definição da resolução de micropassos para fresadora

Segundo (NARDI, 2020a), a definição do valor de passos por milímetro adotado por uma fresadora CNC depende de sua finalidade e está diretamente relacionada às características do fuso, dos drivers e dos motores utilizados em cada eixo. No caso da fresadora proposta, foi definida a resolução de micropassos de 1/4 para todos os eixos, ou seja, Nmicrosteps = 4. Essa resolução é suficiente para garantir uma boa precisão na fabricação de antenas e outros circuitos impressos.

Para essa configuração, os pinos M0, M1 e M2 de cada driver A4988 na CNC Shield devem ser ajustados conforme indicado na linha 3 do Quadro 1. O ajuste foi realizado com o encaixe de jumpers (de cor azul) nos pinos que devem receber nível lógico alto, conforme mostrado na Figura 36.

Quadro 1 – Configurações de resolução de micropassos disponíveis para driver A4988

Nº | MS0 | MS1 | MS2 | Resolução | Nmicrosteps
1 | Low | Low | Low | 1 | 1
2 | High | Low | Low | 1/2 | 2
3 | Low | High | Low | 1/4 | 4
4 | High | High | Low | 1/8 | 8
5 | High | High | High | 1/16 | 16
Fonte: Adaptado de (MICROSYSTEMS, 2015)

3.4.6.2 Instalação da CNC Shield e drivers A4988

A montagem principal iniciou-se com o encaixe da CNC Shield sobre o Arduino Uno, utilizando os pinos padronizados que garantem o alinhamento correto das conexões, conforme apresentado na Figura 37.

Figura 36 – Imagem ilustrativa da CNC Shield com jumpers (de cor azul)

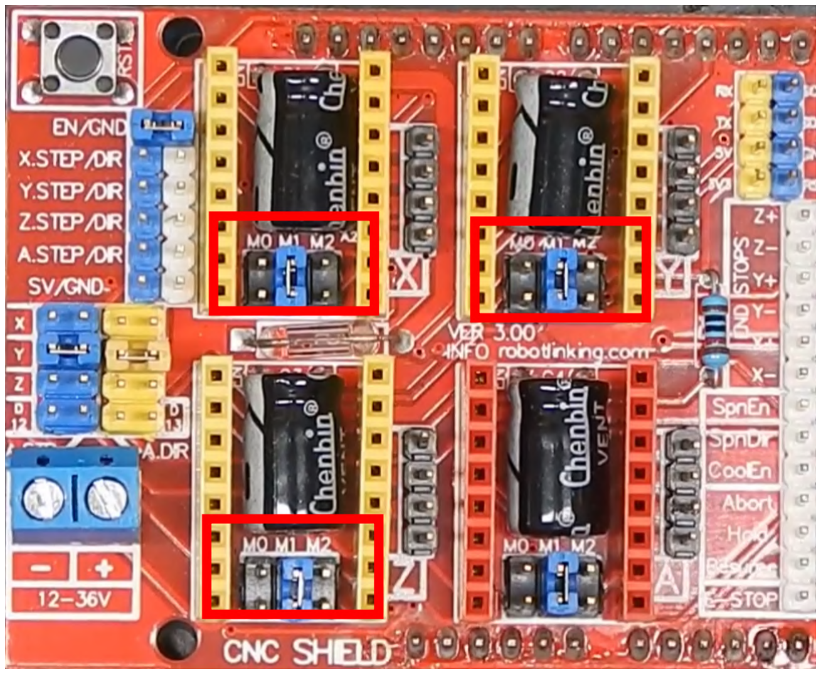
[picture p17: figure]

Fonte: Elaborada pelo autor.

Figura 37 – Imagem ilustrativa da CNC Shield conectada ao Arduino uno

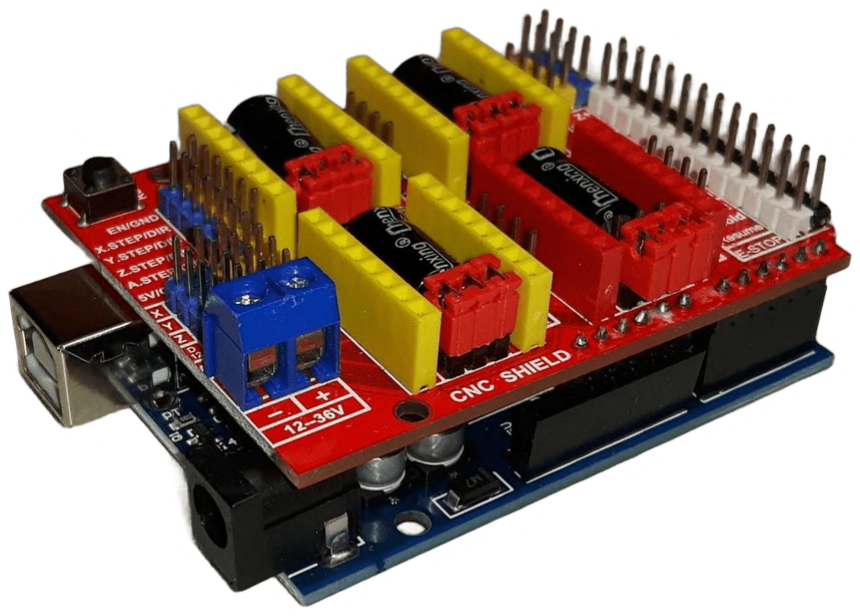
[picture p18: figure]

Fonte: Elaborada pelo autor.

Em seguida, os drivers A4988 foram instalados nos respectivos encaixes da CNC Shield. Antes da instalação, cada driver recebeu a colagem de um dissipador de calor, resultando no conjunto final ilustrado na Figura 38.

3.4.6.3 Cálculo e configuração do Vref nos drivers A4988

Para que a resolução de micropassos definida seja executada corretamente, cada driver deve fornecer ao motor Nema 17 a corrente adequada. Assim, foi necessário calcular e ajustar a tensão de referência (Vref ) de cada driver. Conforme o datasheet do A4988 (MICROSYSTEMS, 2015), o cálculo é realizado pela Equação 3.1.

Figura 38 – Imagem ilustrativa do conjunto CNC Shield e drivers

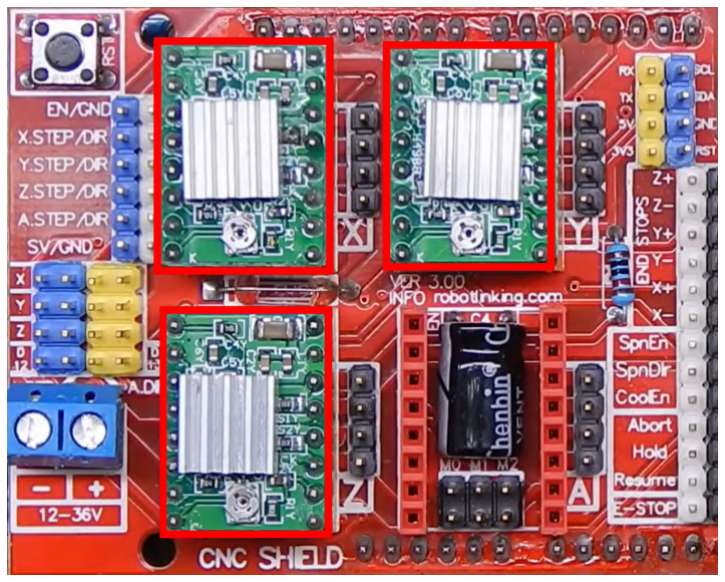
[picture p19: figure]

Fonte: Elaborada pelo autor.

Vref = 8ImaxRs | (3.1)

Em que Imax é a corrente máxima por bobina do motor e Rs é a resistência do resistor do sensor do driver. Para o motor Nema 17 utilizado, tem-se Imax = 1 A, e para o driver A4988, o resistor R100 corresponde a Rs = 0,1 Ω. Substituindo na equação, obtém-se V ref = 0,8 V (ou 800 mV).

Cada driver possui um trimpot para ajuste do Vref . Para a configuração, energizouse o conjunto (Arduino + CNC Shield + drivers) via Universal Serial Bus (USB) conectado à um computador. Com um multímetro em escala de medida de tensão para corrente contínua (DC), posicionou-se a ponteira negativa no GND da CNC Shield e a ponteira positiva sobre o trimpot do driver (veja Figura 39). Assim, foi possível ajustar o valor com uma chave até atingir a tensão calculada (800 mV).

3.4.6.4 Conexão dos motores Nema 17 na CNC Shield

Para a conexão dos motores, foram utilizados cabos flat de 4 vias, com bitola de 0,5 mm²
, dimensionados para alcançar o gabinete do Arduino a partir de cada eixo. A passagem dos cabos foi organizada nos canais dos perfis de alumínio, garantindo proteção e melhor acabamento. O esquema de ligação entre cada motor e seus respectivos pinos dos drivers na CNC Shield está ilustrado na Figura 40.

3.4.6.5 Instalação das chaves de fim de curso

Com base nas dimensões dos cursos totais de cada eixo definidos na subseção 3.3.2, foram escolhidas as posições para a instalação dos pares de chaves de fim de curso. A

Figura 39 – Imagem ilustrativa do ajuste de (Vref ) do driver A4988

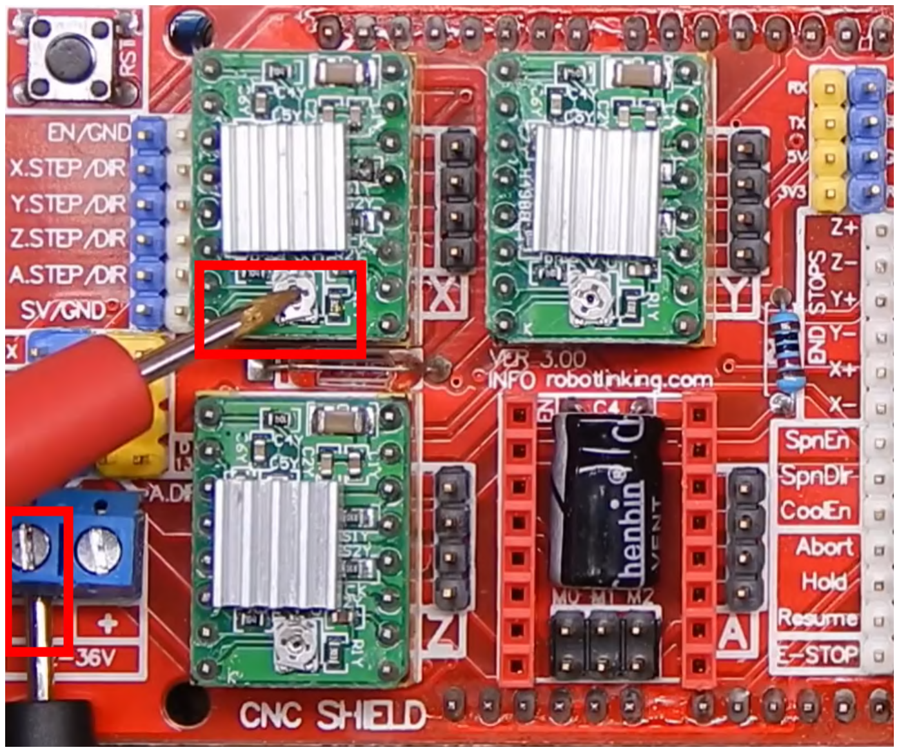
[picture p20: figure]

Fonte: Elaborada pelo autor.

fixação foi realizada de forma que as extremidades das mesas, ao atingir o limite do movimento, acionassem as chaves correspondentes. Em seguida, as conexões elétricas entre as chaves e a CNC Shield foram realizadas conforme o esquemático apresentado na Figura 41. O padrão escolhido para o tipo das conexões foi considerando as chaves em normalmente fechadas (NC) para caso um dos fios se rompa, o firmware identifique e pare a execução para evitar danificar algum componente. Note que a figura é ilustrativa e apresenta as conexões diretamente no Arduino, porém as conexões reais foram feitas nos respectivos pinos da CNC Shield, uma vez que os pinos são replicados do Arduino para CNC Shield.

3.4.7 Instalação dos componentes do sistema de usinagem

A instalação dos componentes do sistema de usinagem seguiu a relação de materiais apresentada no Quadro 8 e envolveu três etapas principais: montagem do conjunto spindle, fixação do conjunto na mesa do eixo Z e realização das conexões elétricas entre o módulo relé, a CNC Shield e o motor 775.

A montagem do conjunto spindle foi iniciada pelo acoplamento e fixação do suporte de pinça ER11 ao eixo do motor 775, conforme ilustrado na Figura 42. Em seguida, o conjunto foi instalado na mesa do eixo Z utilizando um suporte customizado, fabricado por impressão 3D e disponibilizado no arquivo suporte-775.stl.

Figura 40 – Esquemático do circuito para conexão dos motores à CNC Shield

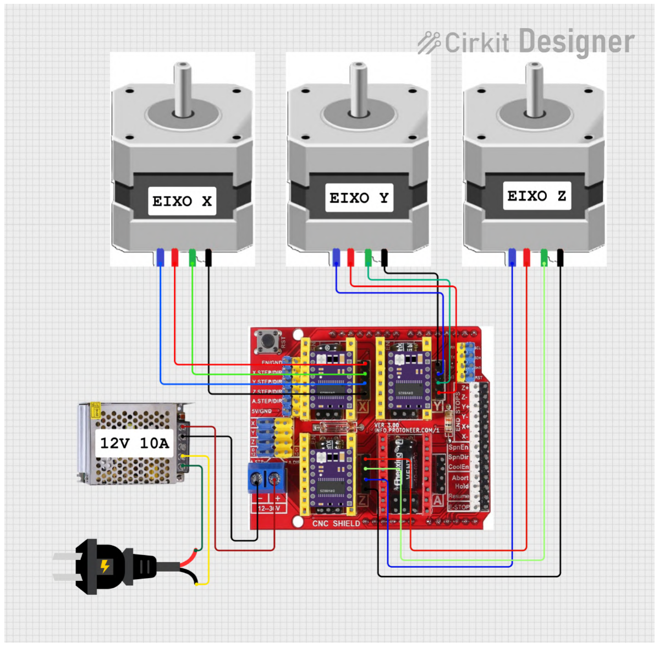
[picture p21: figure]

Fonte: Elaborada pelo autor.

Após a fixação mecânica, procedeu-se à instalação elétrica do spindle. Os terminais positivo e negativo do motor 775 foram conectados ao módulo de relé, o qual, por sua vez, foi ligado à CNC Shield e à fonte de alimentação. Esse arranjo permite o acionamento do motor a partir dos comandos enviados pelo firmware da máquina. O esquemático completo desse circuito é apresentado na Figura 43.

3.4.8 Instalação e configuração do firmware Grbl

Após a instalação completa dos sistemas mecânicos e dos componentes de hardware, iniciaram-se as etapas finais do processo de montagem e configuração: a instalação e a parametrização do firmware Grbl⁶ na placa controladora Arduino Uno. Este firmware

6 https://github.com/gnea/grbl

Figura 41 – Esquemático do circuito para conexão das chaves de fim de curso

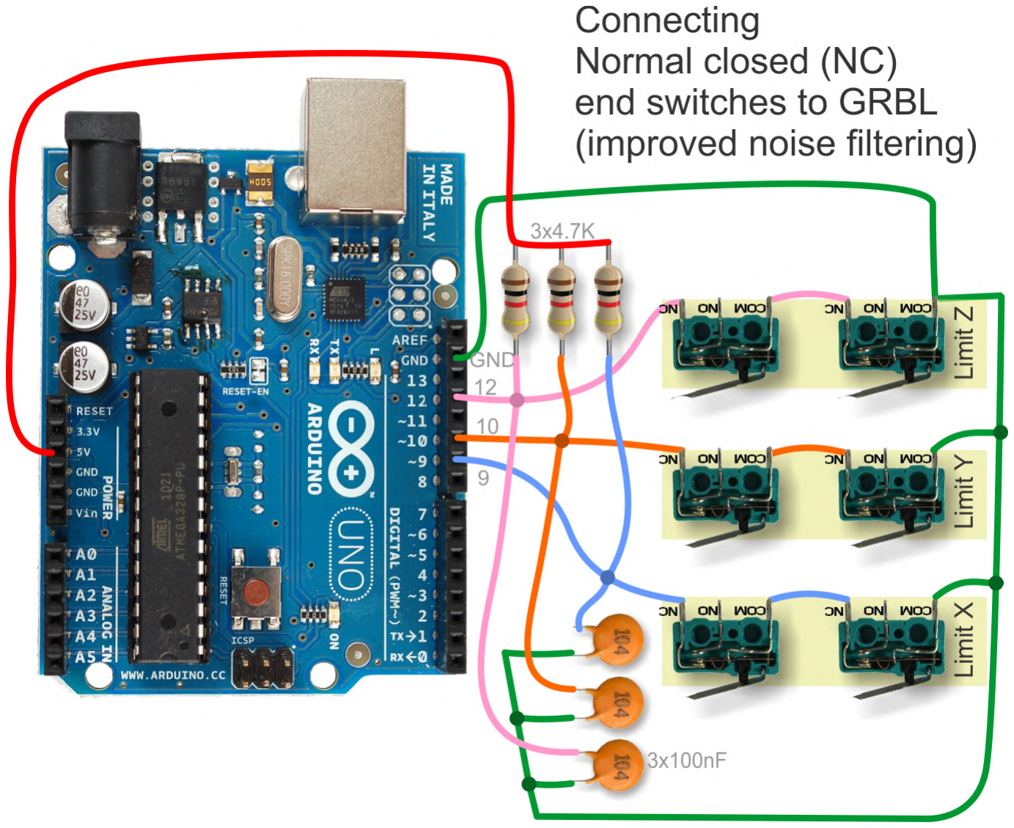
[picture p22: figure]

Fonte: https://github.com/gnea/grbl/wiki/Wiring-Limit-Switches, acessado em 12/10/2025.

Figura 42 – Imagem ilustrativa do conjunto spindle montado

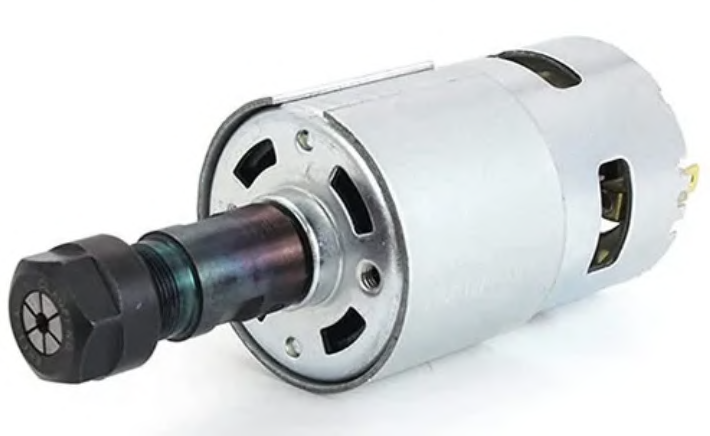
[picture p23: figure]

Fonte: Elaborada pelo autor.

é responsável por receber códigos G-Code enviados pela porta serial e traduzi-los em comandos elétricos para os motores por meio da CNC Shield.

As etapas de instalação e a parametrização do firmware são descritas a seguir e foram executadas a partir de um computador conectado ao Arduino Uno via porta USB, utilizando o sistema operacional Ubuntu Linux 22.04. As seções seguintes detalham os procedimentos realizados, assim como o Apêndice C que apresenta o passo a passo com

Figura 43 – Esquemático do circuito do spindle com módulo relé e CNC Shield

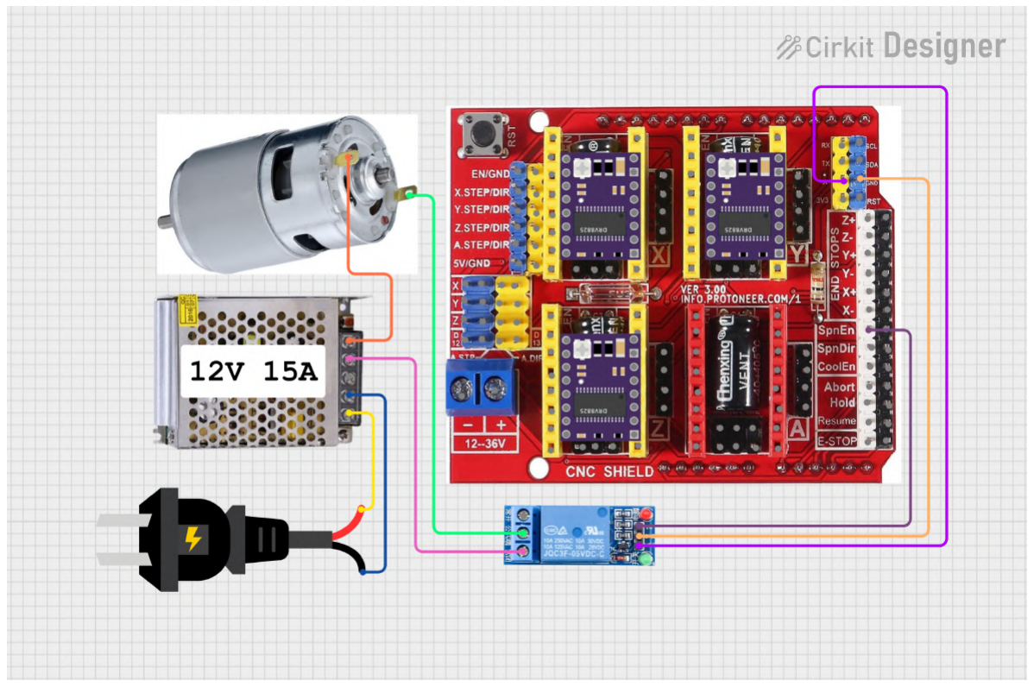
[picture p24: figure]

Fonte: Elaborada pelo autor.

capturas de tela.

3.4.8.1 Instalação do firmware

Para a instalação do firmware, foi inicialmente configurado no computador o software Arduino IDE⁷
, versão 2.3.6, utilizado para compilar e carregar o código do Grbl no microcontrolador. A configuração da placa Arduino Uno conectada ao computador foi realizada na IDE executando os seguitnes passos:
- Passo 1 — Menu Tools > Board > Arduino AVR Boards > Arduino Uno;
- Passo 2 — Menu Tools > Port > /dev/ttyACM0 (Arduino Uno).

A versão do firmware adotada no projeto foi a Grbl v1.1h⁸
. O arquivo compactado
contendo o código-fonte foi utilizado e está disponível no repositório Github deste projeto¹ ,
com o nome grbl-v1.1h.zip. Após a extração, o código-fonte foi importado para IDE do Arduino acessando o menu File > Open e selecionando o arquivo grbl.ino localizado em "grbl-v1.1h/grbl/".

Antes da compilação e do carregamento do firmware, foram realizadas duas alterações no código-fonte, necessárias para adaptar configurações estáticas do Grbl às

7 | https://www.arduino.cc/en/software/
8 | https://github.com/gnea/grbl/releases/tag/v1.1h.20190825

características específicas da fresadora CNC desenvolvida. As modificações realizadas ajustam as seguintes características:

- Desabilitar o controle de velocidade do conjunto spindle (motor 775 + suporte

ER11 ), uma vez que essa característica está habilitada por padrão no firmware, mas o projeto não utiliza um driver eletrônico dedicado para variação de rotação;

- Inverter a lógica do pino de acionamento do spindle, pois o módulo relé utilizado na

fresadora desenvolvida foi configurado modo “normalmente aberto”, que é diferente da configuração padrão do Grbl.

Esses ajustes foram feitos no arquivo config.h, conforme apresentado no Código 3.1. Finalizadas as modificações, o código foi compilado e carregado na placa Arduino Uno, concluindo a etapa de instalação do firmware.

Código 3.1 – Configurações padrão do Grbl ajustadas para o projeto

1 | //#define VARIABLE_SPINDLE // Default enabled. Comment to disable.
2 | #define INVERT_SPINDLE_ENABLE_PIN // Default disabled. Uncomment to enable.

3.4.8.2 Parametrização do firmware

A etapa de parametrização do firmware Grbl tem como objetivo ajustar as características específicas da fresadora CNC desenvolvida, como as dimensões físicas dos cursos dos eixos, o comportamento elétrico dos motores e demais particularidades do projeto. Diferentemente das configurações estáticas alteradas diretamente no arquivo config.h (veja subseção 3.4.8.1), os parâmetros de operação são definidos dinamicamente, utilizando comandos próprios do Grbl enviados via comunicação serial.

Para esse processo, foi utilizado o software Universal Gcode Sender (UGS), versão
2.1.17. O Universal Gcode Sender (UGS) é uma ferramenta amplamente empregada para controle de máquinas CNC, suportando diversos firmwares, incluindo o Grbl. A versão utilizada neste projeto inclui uma interface gráfica com funcionalidades como: envio de comandos manuais, carregamento de arquivos G-code, visualização de trajetórias e ferramentas de importação e conversão de arquivos nos formatos SVG/DXF/PNG/JPG. O pacote built-in, contendo todas as dependências necessárias, está disponível para download no próprio site⁹ do projeto e também foi incluído no repositório Github deste trabalho¹

com o nome linux-x64-ugs-v2.1.17.zip.

Ao abrir o UGS com o Arduino Uno conectado ao computador via porta USB, realizou-se a configuração inicial da comunicação. Foram selecionados o tipo de firmware

9 https://universalgcodesender.com/

(GRBL), a porta serial (ttyACM0) correspondente ao Arduino e a taxa de transmissão -baud rate (115200). Após as configurações, foi possível executar a conexão e confirmar no console do software UGS a comunicação estabelecida com sucesso.

Embora os parâmetros do firmware Grbl possam ser modificados diretamente através de comandos digitados no console, a versão do UGS utilizada oferece uma interface mais prática para alteração desses valores. Essa funcionalidade pode ser acessada no software através do menu Machine > Firmware Settings, onde é exibida uma tabela contendo todos os parâmetros configuráveis. A tabela exibida pelo UGS é composta por três colunas:

- Setting — identificador do parâmetro, composto pelo símbolo ‘$‘ seguido de um

número;

- Value — valor atual aplicado à configuração do parâmetro;
- Description — descrição da função correspondente no firmware.

Para a fresadora CNC desenvolvida neste projeto, alguns parâmetros precisaram ser ajustados em relação aos valores padrões, de forma a representar corretamente as características mecânicas e geométricas da máquina. Entre esses parâmetros, destaca-se o valor de steps/mm, que define quantos passos o motor deve executar para produzir um deslocamento linear de 1 mm em determinado eixo.

Conforme indicado na documentação¹⁰ do próprio firmware, o valor de steps/mm pode ser calculado pela Equação 3.2. As variáveis envolvidas nesse cálculo, bem como os valores utilizados na fresadora deste trabalho, estão apresentadas na Tabela 4.

Vsteps/mm =

Nsteps/rev × Nmicrosteps

Dmm/rev

(3.2)

Tabela 4 – Descrição e valores das variáveis utilizadas no cálculo de steps/mm

Variável | Descrição | Valor
Nsteps/rev | Número de passos completos por revolução do motor de passo. Obtido da especificação do motor Nema 17 (veja subseção 3.2.2.2).

200

Nmicrosteps | Número de microsteps configurados no driver (veja subseção 3.4.6.1). | 4
Dmm/rev | Distância percorrida (mm) a cada revolução do fuso. Obtido da especificação do fuso (veja subseção 3.2.1.2). | 8
Vsteps/mm | Resultado do cálculo de passos por milímetro, obtido pela aplicação da Equação 3.2 com os valores indicados nesta tabela. | 100

Fonte: Elaborada pelo autor.

10 https://github.com/gnea/grbl/wiki/Grbl-v1.1-Configuration

Além do parâmetro descrito anteriormente, os ajustes apresentados na Tabela 5 reúnem as configurações essenciais para o funcionamento da fresadora CNC desenvolvida. Esses ajustes incluem inversões de direção para adequação ao arranjo mecânico final, definição de velocidades e acelerações, determinados experimentalmente para garantir movimentos estáveis, e os limites de curso dos eixos que estabelecem a área útil de trabalho. Todos os valores foram configurados conforme as características da estrutura mecânica e dos componentes utilizado, compondo a lista final de parametrizações alteradas do padrão presente no firmware Grbl.

Tabela 5 – Parâmetros ajustados no firmware Grbl para fresadora desenvolvida

Parâmetro | Valor | Descrição
$5 | 1 | Inverte a lógica dos pinos das chaves de limite. Requer chaves instaladas.
$21 | 1 | Ativa os limites de hardware (hard limits). Requer chaves de fim de curso instaladas e operacionais.
$22 | 1 | Ativa o ciclo de homing. Requer chaves de fim de curso e $21 habilitado.
$23 | 3 | Inverte a direção de busca do homing para eixos com chaves instaladas no sentido negativo.
$100 | 100 | Número de passos por milímetro (steps/mm) do eixo X. Definido pelas características mecânicas e pelo motor.
$101 | 100 | Número de passos por milímetro (steps/mm) do eixo Y. Definido pelas características mecânicas e pelo motor.
$102 | 100 | Número de passos por milímetro (steps/mm) do eixo Z. Definido pelas características mecânicas e pelo motor.
$130 | 150 | Curso máximo do eixo X, em milímetros. Corresponde à área útil definida na subseção 3.3.1.
$131 | 150 | Curso máximo do eixo Y, em milímetros. Corresponde à área útil definida na subseção 3.3.1.
$132 | 50 | Curso máximo do eixo Z, em milímetros. Definido após a montagem do conjunto mecânico.

Fonte: Elaborada pelo autor.

Após a definição de todos os valores no software UGS, as configurações são gravadas na memória não volátil do Arduino Uno. Isso garante que os parâmetros permaneçam armazenados mesmo após o desligamento da máquina, sendo substituídos apenas caso novos ajustes sejam realizados ou o firmware seja recarregado.

Com esse procedimento concluído, a parametrização do firmware Grbl foi finalizada, deixando a fresadora CNC operacional. A partir desse ponto, a máquina CNC pode ser utilizada para a fabricação de protótipos de antenas planares ou PCIs, conforme os procedimentos de operação apresentados na próxima seção.

## 3.5 ELABORAÇÃO DO GUIA DE OPERAÇÃO

Considerando que a fresadora será utilizada em atividades de ensino e pesquisa, elaborou-se um guia de operação, estruturado com as seguintes orientações:

- cuidados de segurança durante a operação;
- procedimentos de inicialização e desligamento da máquina;
- fixação do substrato na mesa de trabalho;
- carregamento e execução de arquivos G-code com o software UGS;
- calibração e ajuste dos eixos;
- manutenção preventiva (limpeza, lubrificação dos eixos e substituição de ferramentas).

Esse guia tem como propósito garantir que estudantes e pesquisadores utilizem a fresadora de forma segura, além de contribuir para a durabilidade e confiabilidade da máquina. O guia completo encontra-se disponível no Apêndice D, permitindo consulta detalhada sempre que necessário.

# 4 RESULTADOS

Este capítulo apresenta os resultados obtidos com o desenvolvimento da fresadora CNC proposta neste trabalho. A máquina foi integralmente montada, configurada e validada quanto à sua estrutura mecânica, sistemas eletrônicos e de controle, porém algumas limitações foram identificadas durante os testes finais de operação, as quais são descritas nas próximas seções.

## 4.1 ANÁLISE DAS SOLUÇÕES E DEFINIÇÃO DOS COMPONEN-

## TES

A análise das três soluções apresentadas nos trabalhos relacionados (ver seção 2.5) resultou no levantamento de boas práticas de projeto, configurações mecânicas e estratégias de montagem amplamente utilizadas em máquinas CNC de pequeno porte. Esse estudo comparativo também permitiu a definição dos requisitos a serem seguidos na construção da fresadora. A partir dessa análise, foram selecionados os componentes mecânicos, eletrônicos e o firmware de controle, todos facilmente encontrados no mercado.

## 4.2 MODELAGEM, MONTAGEM E CONFIGURAÇÃO

As figuras 44 e 45 apresentam imagens da fresadora CNC construída a partir dos componentes definidos, seguindo o modelo 3D desenvolvido na etapa de modelagem (veja seção 3.3). A montagem resultou em uma estrutura final com rigidez adequada, bom alinhamento entre os eixos e precisão compatível com CNCs para fins acadêmicos.

O firmware Grbl foi instalado e configurado corretamente, incluindo parametrizações de velocidade, aceleração, steps/mm, lógica das chaves de fim de curso e limites de deslocamento. com as parametrizações, foi possível verificar uma comunicação estável entre o Arduino Uno e o software Universal Gcode Sender (UGS), permitindo controle completo da máquina.

## 4.3 TESTES DE VALIDAÇÃO DA CNC

Esta seção apresenta os principais resultados obtidos durante os testes de validação da fresadora CNC. Esses testes permitiram verificar o desempenho mecânico e eletrônico da máquina, bem como os ajustes ainda necessários para a conclusão da etapa de fabricação real.

Figura 44 – Imagem da vista frontal da fresadora CNC desenvolvida

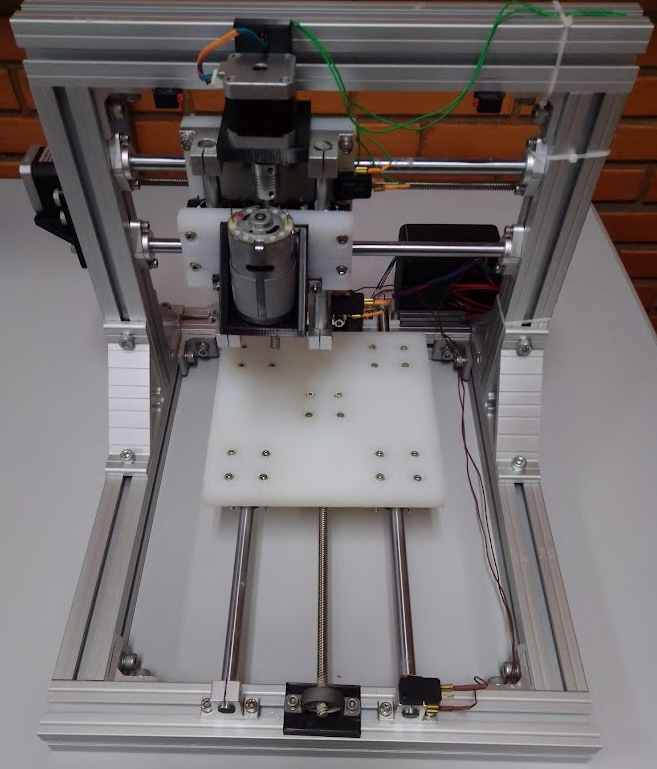
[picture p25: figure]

Fonte: Elaborada pelo autor.

4.3.1 Adaptação para mecanismo de fixação

Durante a preparação para os testes, foi identificado que a modelagem do sistema mecânico inicial não previa um mecanismo para fixação das placas de fenolite ou outros substratos. Para possibilitar a operação, utilizou-se uma solução temporária baseada na instalação de uma mesa de sacrifício.

Foi utilizada uma placa de MDF de 9 mm de espessura, com as mesmas dimensões da mesa de trabalho, parafusada sobre a placa de Nylon. Essa base permitiu a fixação segura das placas de fenolite com parafusos e arruelas, sem risco de danificar a mesa principal.

4.3.2 Validações de comandos

Antes da execução de um teste de fabricação real, foram realizados ensaios de deslocamento, homing, zeramento de coordenadas e execução de comandos de G-code. Durante essa etapa, verificou-se um problema significativo no conjunto spindle formado pelo motor 775 e o suporte ER11.

Ao acionar o motor, ocorreram vibrações excessivas que geravam falsos acionamentos nas chaves de fim de curso, levando o firmware a executar o bloqueio de segurança. A análise revelou que o suporte ER11 apresentava desalinhamento em relação ao eixo do motor, possivelmente devido a deformação de fabricação ou erro na montagem. Esse

Figura 45 – Imagem da vista posterior da fresadora CNC desenvolvida

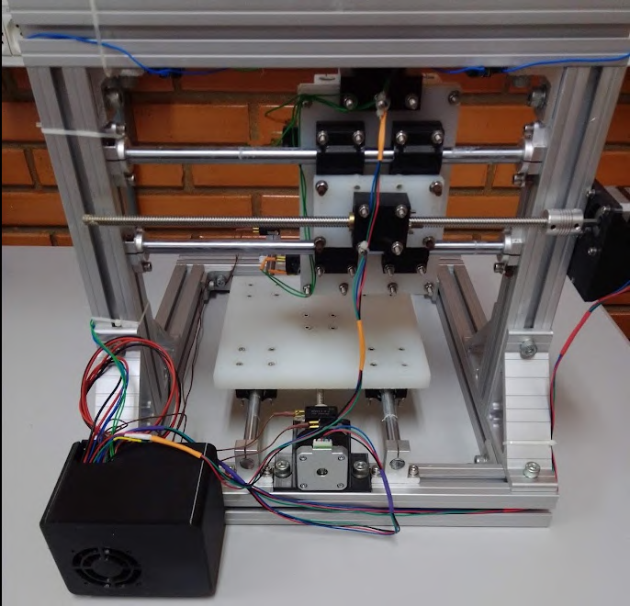
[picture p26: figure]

Fonte: Elaborada pelo autor.

problema impossibilitava a continuação dos testes de validação de comandos e de fabricação de um protótipo de antena, deixando um dos objetivos específicos sem ser atingido.

Como medida provisória para continuidade das validações de comandos, o conjunto spindle foi removido e desativado na configuração do firmware. Com isso, os testes de movimentação, homing e execução de trajetórias puderam ser concluídos sem falhas, validando o sistema mecânico e o controle eletrônico.

4.3.3 Simulação do processo de fabricação

Apesar da impossibilidade de realizar a usinagem real de protótipos de antenas ou de PCIs devido ao problema no suporte ER11, foi realizada a simulação completa do processo de fabricação. Um arquivo G-code de teste foi carregado no software UGS e executado sem acionamento do motor de usinagem.

A fresadora realizou todos os deslocamentos previstos, respeitando as trajetórias e velocidades definidas sem interrupções. Essa validação confirmou que a máquina CNC encontra-se mecânica e eletronicamente funcional e preparada para o processo de fabricação, restando apenas a substituição do suporte ER11 para permitir a etapa final de usinagem real.

# 5 CONCLUSÕES

Este trabalho apresentou o desenvolvimento de uma fresadora CNC de pequeno porte destinada à fabricação de antenas planares e Placa de Circuito Impressos (PCIs) para fins didáticos e de pesquisa no câmpus São José do Instituto Federal de Santa Catarina (IFSC). O desenvolvimento incluiu etapas como: análise de soluções semelhantes e definição de componentes, modelagem tridimensional em software CAD, montagem física, configuração de firmware e validação dos sistemas da fresadora. Foram envolvidos conhecimentos multidisciplinares das áreas de eletrônica, mecânica, automação e telecomunicações.

A análise de soluções existentes e o estudo de trabalhos relacionados permitiram identificar boas práticas e requisitos relevantes para máquinas CNC de pequeno porte alinhados aos objetivos do projeto, fornecendo um conhecimento sólido para a definição dos componentes e das estratégias de montagem.

A adoção do software CAD Sketchup para a modelagem tridimensional mostrou-se essencial para o sucesso do projeto. A etapa de modelagem permitiu ajustar dimensões, definir disposição física dos elementos, verificar interferências entre componentes, avaliar o percurso dos eixos e antecipar problemas de montagem. Esse processo reduziu retrabalhos, otimizou o uso dos materiais e contribuiu para uma execução organizada de todas as fases subsequentes.

Os resultados apresentados no Capítulo 4 mostram que a máquina foi projetada, montada e configurada adequadamente, atendendo a todos os requisitos estruturais, eletrônicos e de controle previstos. O firmware Grbl foi instalado e parametrizado com sucesso, e a comunicação com o software Universal Gcode Sender (UGS) demonstrou estabilidade e precisão na interpretação dos comandos.

Na etapa final de testes, foi identificado um desalinhamento no sistema de usinagem baseado no motor 775 e suporte ER11, o que impediu a fabricação real de um protótipo de antena. Ainda assim, as validações mecânica, eletrônica e de controle foram concluídas com sucesso. As simulações completas de G-code demonstraram que a CNC executa corretamente as trajetórias programadas, estando pronta para operar após a substituição do suporte ER11.

De modo geral, os resultados obtidos demonstram que a fresadora CNC desenvolvida atende aos objetivos e requisitos do projeto, representando uma contribuição significativa para o desenvolvimento de pesquisas e atividades didáticas nas áreas de telecomunicações do câmpus São José do IFSC. Sua utilização possibilitará a fabricação de protótipos de antenas e PCIs em projetos de ensino, pesquisa e extensão.

## 5.1 TRABALHOS FUTUROS

Como continuidade deste trabalho, diversas melhorias e extensões podem ser consideradas visando o aprimoramento do desempenho, da precisão e da usabilidade da fresadora. Entre as principais indicações de trabalhos futuros, destacam-se:

- Substituição do suporte ER11 para viabilizar a fabricação real de protótipos de

antenas e outros circuitos impressos;

- Implementação de um mecanismo definitivo para fixação das peças na mesa de

trabalho;

- Implementação de um sistema de parada de emergência para desligamento imediato

da fresadora CNC;

- Desenvolvimento de um gabinete de proteção para a fresadora, visando maior

segurança do operador e contenção de resíduos;

- Integração de um sistema de controle de velocidade do spindle, possibilitando ajustes

mais adequados ao tipo de material e à ferramenta utilizada;

- Desenvolvimento de uma interface dedicada de controle, permitindo a operação da

CNC sem a necessidade de um computador externo.

Essas melhorias ampliam a robustez, segurança e usabilidade da fresadora, consolidando seu uso em atividades de pesquisa, ensino e prototipagem nas disciplinas de telecomunicações no câmpus São José do Instituto Federal de Santa Catarina (IFSC).

# REFERÊNCIAS

AMORIM, E. A. P.; FILHO, J. F. V. R.; ROSA, M. V. D. O. G. Desenvolvimento de uma máquina CNC sem estrutura de apoio fixa com estrutura do eixo X acoplável e estrutura do eixo Y extensível. 88 f. Monografia (Bacharel em Engenharia da Computação) — Universidade Estadual do Maranhão, São Luís, 2019. 16

AZEVEDO, D. F. O. Linguagem de programação. 2013. Disponível em: <https: //www.domingosdeazevedo.com/cam/ling5>. Acesso em: 13 dez 2023. 16

CAVENAGHI, B. A. de G.; CAVENAGHI, C. A. de G.; GONZALEZ, J. F. P. Desenvolvimento de uma máquina fresadora CNC multifunção de baixo custo. Revista Mackenzie de Engenharia e Computação, GN1 Sistemas e Publicacoes Ltd., v. 22, n. 1, 2022. Disponível em: <https://doi.org/10.5935/rmec.v22n1p197-224>. 14, 19, 21, 23, 26, 27

COSTA, A. R. Otimização do Processo de Fresamento de Cavidades com Fresas de Insertos Intercambiáveis. 106 p. Dissertação (Mestrado) — Universidade Estadual de Campinas, Faculdade de Engenharia Mecânica, Campinas, 2003. 14, 17, 27

LEAL, J. F.; RIBAS, M. T. Fresadora CNC microcontroladora para confecção de placas de circuito impresso. 69 f. Monografia (Tecnólogo em Mecatrônica Industrial) — Universidade Tecnológica Federal do Paraná, Curitiba, 2015. 17, 18, 19, 20, 21, 22, 23, 24, 25, 26, 28, 31

LIU, J. et al. Future paper based printed circuit boards for green electronics: fabrication and life cycle assessment. Energy Environ. Sci., v. 7, p. 3674–3682, 2014. ISSN 1754-5692. 25

MICROSYSTEMS, A. A4988 DMOS Microstepping Driver with Translator and Over-current Protection — Datasheet. Worcester, MA, USA, 2015. Available at: <https://www.alldatasheet.com/datasheet-pdf/view/338780/ALLEGRO/A4988.html> (accessed 2025-11-22). 45, 46

NARDI, M. Construa sua Própria CNC 2.0. 2018. Acesso em: 14
jun. 2025. Disponível em: <https://www.youtube.com/playlist?list=PLFaCm8C4CKG9-HOPlHiShVIihmY6uEM3v>. (https://www.youtube.com/playlist?list=PLFaCm8C4CKG9-HOPlHiShVIihmY6uEM3v) 27

NARDI, M. Construa sua própria CNC 3.0. 2018. Acesso em: 14 jun. 2025. Disponível em: <https://www.youtube.com/playlist?list=PLFaCm8C4CKG90CCVCxJjJ7HpFf0Ofe1hz>. (https://www.youtube.com/playlist?list=PLFaCm8C4CKG90CCVCxJjJ7HpFf0Ofe1hz) 19, 20, 27

NARDI, M. Construa sua própria CNC 2.1 com Arduino. 2020. Acesso em: 14 jun. 2025. Disponível em: <https://marlonnardi.com/2020/06/15/como-fazer-sua-propria-cnc-caseira-com-arduino-cnc-2-1-marlon-nardi/>. (https://marlonnardi.com/2020/06/15/como-fazer-sua-propria-cnc-caseira-com-arduino-cnc-2-1-marlon-nardi/) 27, 45

NARDI, M. Construa sua própria CNC 3.0 com Arduino. 2020. Acesso em: 14 jun. 2025. Disponível em: <https://marlonnardi.com/2020/06/16/construa-sua-propria-cnc-3-0-com-arduino/>. (https://marlonnardi.com/2020/06/16/construa-sua-propria-cnc-3-0-com-arduino/) 19, 27

OLIVEIRA, E. E. C. de. Antenas de Microfita com Patch Quase-fractal para Aplicações em Redes WPAN/WLAN. 125 p. Dissertação (Mestrado) — Universidade Federal do Rio Grande do Norte, Natal, 2008. Disponível em: <https://repositorio.ufrn.br/bitstream/123456789/15213/1/ElderECO.pdf>. (https://repositorio.ufrn.br/bitstream/123456789/15213/1/ElderECO.pdf) 13

PIRES, D. A.; SILVA, H. J. D. Desenvolvimento de antenas impressas em substrato de fenolite. In: . [S.l.: s.n.], 2017. 13

POLASTRINI, F. H. Desenvolvimento de uma Máquina CNC de Baixo Custo com Software e Hardware Abertos. 100 f. Monografia (Bacharel em Engenharia Elétrica) — Instituto Federal de Minas Gerais Câmpus Formiga, Formiga, 2016. 13, 16, 18, 19, 20, 21, 22, 23, 24, 25, 26, 27, 29

RODRIGUES, L. et al. Fabricação de placa de circuito impresso (pci) usando método fotográfico e redução significativa de soluções químicas. Notas Técnicas, v. 9, p. 26–33, 4 2019. ISSN 22367640. 25

SANCHES, J. M. Desenvolvimento de uma fresadora CNC de baixo custo para fins didáticos. 119 p. Dissertação (Mestrado) — Universidade de São Paulo, São Carlos, 2009. 17, 19, 21, 22

SOUSA, P. R. D. et al. Placas de circuito impresso: Mercado atual e perspectivas. BNDES Setorial, v. 14, n. 1, 2001. Disponível em: <https://web.bndes.gov.br/bib/jspui/handle/1408/13440>. (https://web.bndes.gov.br/bib/jspui/handle/1408/13440) 25

# Apêndices

# APÊNDICE A – LISTA DE

# COMPONENTES UTILIZADOS

Este apêndice apresenta a lista completa dos componentes utilizados na construção da fresadora CNC proposta, organizada em duas seções principais: componentes mecânicos e componentes de hardware. Além da relação dos itens com suas respectivas quantidades, observações e custos, incluem-se imagens ilustrativas contendo as dimensões dos principais elementos mecânicos.
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

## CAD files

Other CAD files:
modelagem/fontes-stl/mancal/base-mancal-1.stl
modelagem/fontes-stl/SCS12UU/SCS12UU-ROTATE.stl
modelagem/fontes-stl/Suporte-775/775_Motor_Mounting_Bracket_-_Reinforced_v1.1.stl
modelagem/fontes-stl/suporte-nema/supote-nema-1.stl
modelagem/fontes-stl/mancal/base-mancal-2.stl
modelagem/fontes-stl/SCS12UU/sc12uu_imrahil.stl
modelagem/fontes-stl/Suporte-775/775_Motor_Mounting_Bracket_v1.1_.stl
modelagem/fontes-stl/Suporte-castanha/pillow-castanha-antifolga-M4.stl
modelagem/fontes-stl/suporte-nema/suporte-nema-1-v2.stl
modelagem/fontes-stl/SCS12UU/lm12-housing.stl
modelagem/fontes-stl/Suporte-775/Suporte-775.stl
modelagem/fontes-stl/Suporte-castanha/pillow-castanha-antifolga.stl
modelagem/fontes-stl/suporte-nema/supote-nema-2.stl
modelagem/fontes-stl/SCS12UU/Pillow-block-Guia-Furo-M5-lado1.stl
modelagem/fontes-stl/suporte-nema/suporte-nema-3.stl
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

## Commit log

2025-12-12 add repo files and readme
    [775+DC+motor.skp, 775_Motor_Mounting_Bracket_-_Reinforced_v1.1.stl, 775_Motor_Mounting_Bracket_v1.1_.stl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]
2026-09-14 feat: adiciona link para tcc e fotos
